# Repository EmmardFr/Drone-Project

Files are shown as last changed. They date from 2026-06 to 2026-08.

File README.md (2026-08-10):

# Drone-Project

- `Hardware/` contains hardware design files:
  - `Datasheets/`: component datasheets (IMUs, barometers, and related parts) used during hardware selection.
  - `Graphics/`: project graphics and visual assets.
  - `Schematics/`: standalone schematic libraries/references for key components (e.g., sensors and Teensy 4.1).
  - PCB designs, in development order:
    1. `ismd_flight_computer (obselete)/` (deprecated early prototype): initial all-in-one flight-computer concept combining Teensy 4.1, multiple IMU/barometer options, and onboard power circuitry.
    2. `ismd_fc_sensortest/`: dedicated sensor test board used to compare multiple IMU and barometer options around a Teensy 4.1 base.
    3. `Carrier_PCB/`: first carrier board revision for system integration (power distribution, receiver I/O, ESC/motor signal breakout, and module connectors).
    4. `Carrier_PCB_v2/`: second carrier board revision refining the carrier design and production-ready outputs.
- `software/` contains firmware, libraries, and software tooling.

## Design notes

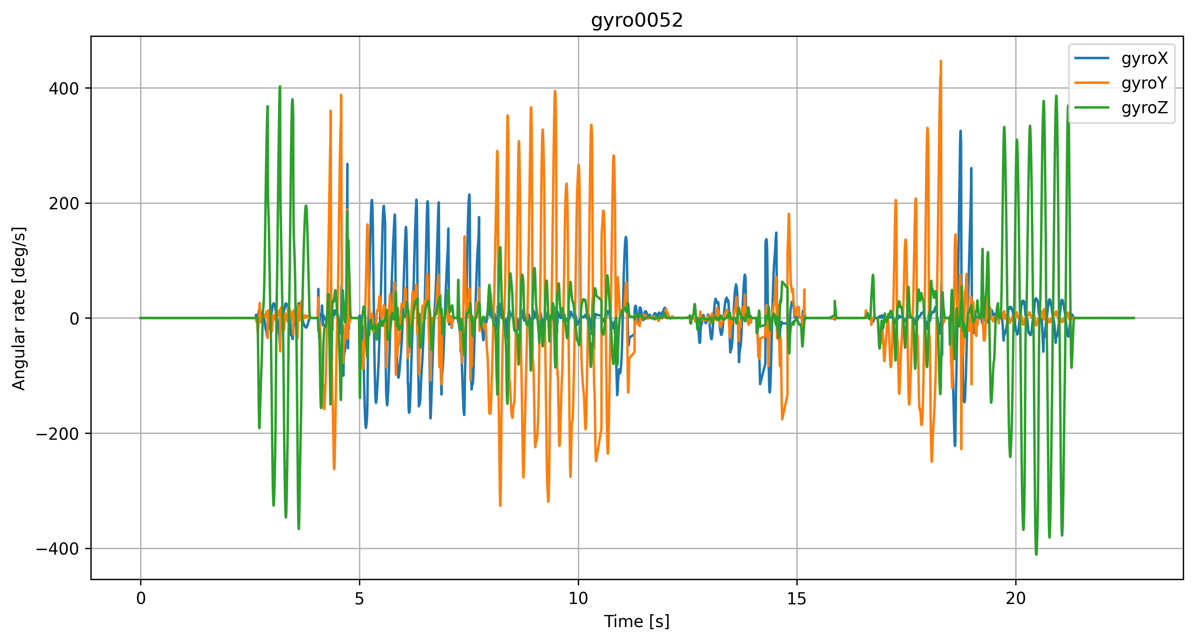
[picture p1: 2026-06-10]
software/Teensy Dev Gyro Plots/gyro0052.png

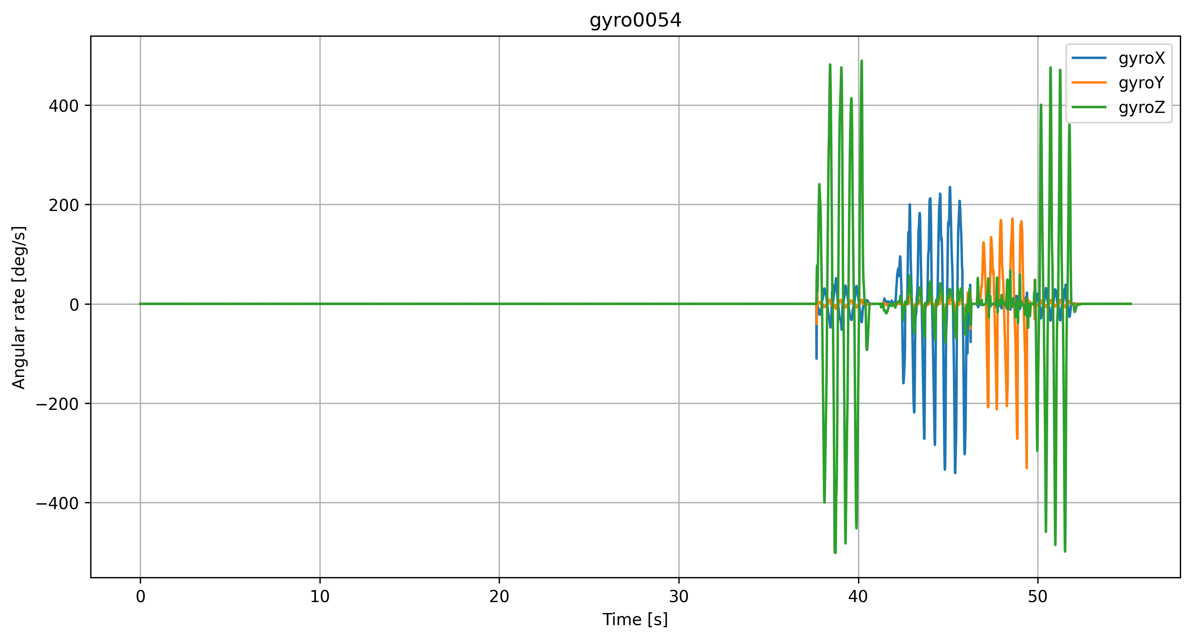
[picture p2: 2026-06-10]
software/Teensy Dev Gyro Plots/gyro0054.png

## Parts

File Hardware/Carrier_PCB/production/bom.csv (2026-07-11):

Designator | Footprint | Quantity | Value | LCSC Part #
3V3, 5V, INT, M1, M2, M3, M4, NCS, SBUS, SCLK, SD0, SDI, SPORT, TLM | TestPoint_Bridge_Pitch2.54mm_Drill0.7mm | 14 | TestPoint
C1 | 1206 | 1 | 10u
C2, C3 | 0805 | 2 | 100n
D1 | 0805 | 1 | LED
ESC1 | PinHeader_1x08_P2.54mm_Horizontal | 1 | Conn_01x08
ESC2 | JST_SH_SM08B-SRSS-TB_1x08-1MP_P1.00mm_Horizontal | 1 | Conn_01x08
GND | PinHeader_1x01_P2.54mm_Horizontal | 1 | Conn_01x01
J1, J2 | PinSocket_1x24_P2.54mm_Vertical | 2 | Conn_01x24
MPU | PinSocket_1x10_P2.54mm_Vertical | 1 | Conn_01x10
R1 | 0805 | 1 | 300
R2 | 0603 | 1 | 10K
R3 | 0603 | 1 | 20K
RXSR_2 | Molex_PicoBlade_53261-0471_1x04-1MP_P1.25mm_Horizontal | 1 | Conn_01x04
RXSR | PinHeader_1x04_P2.54mm_Horizontal | 1 | Conn_01x04

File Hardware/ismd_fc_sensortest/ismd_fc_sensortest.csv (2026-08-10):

Reference | Qty | Value | DNP | Exclude from BOM | Exclude from Board | Footprint | Datasheet
B1 | 1 | BMP581 |  |  |  | BMP581:BMP581
B2 | 1 | DPS368 |  |  |  | DPS368:LGA8S145X65P2X4_200X250X110-V
B3 | 1 | ICP-20100 |  |  |  | ICP-20100:PQFN50P200X200X85-10N
B4 | 1 | MS5611 |  |  |  | MS5611:SON125P500X300X100-8N
B5 | 1 | LPS22DF |  |  |  | Package_LGA:ST_HLGA-10_2x2mm_P0.5mm_LayoutBorder3x2y | https://www.st.com/resource/en/datasheet/lps22df.pdf
C1,C2,C3,C4,C5,C6,C7,C8,C9,C13,C14,C15,C16,C17,C18 | 15 | 100nF |  |  |  | Capacitor_SMD:C_0201_0603Metric
C10 | 1 | 0.1uF |  |  |  | Capacitor_SMD:C_0201_0603Metric
C11 | 1 | 2.2uF |  |  |  | Capacitor_SMD:C_0201_0603Metric
C12 | 1 | 10nF |  |  |  | Capacitor_SMD:C_0201_0603Metric
I1 | 1 | ICM-42688-P |  |  |  | ICM-42688-P:PQFN50P300X250X97-14N
I2 | 1 | BMI088 |  |  |  | Package_LGA:Bosch_LGA-16_4.5x3mm_P0.5mm_LayoutBorder7x1y_ClockwisePinNumbering | https://www.bosch-sensortec.com/media/boschsensortec/downloads/datasheets/bst-bmi088-ds001.pdf
I3 | 1 | BMI270 |  |  |  | BMI270:XDCR_BMI270
I4 | 1 | ISM330DLC |  |  |  | ISM330DLCTR:PQFN50P250X300X86-14N
U1 | 1 | TEENSY_4.1 |  |  |  | TEENSY_4.1:TEENSY41

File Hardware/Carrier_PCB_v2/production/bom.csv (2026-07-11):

Designator | Footprint | Quantity | Value | LCSC Part #
3V1, 5V1, INT1, M1, M2, M3, M4, NCS1, SBUS1, SCLK1, SDI1, SDO1, SPORT1, TLM1 | TestPoint_Keystone_5005-5009_Compact | 14 | 5009
C1 | 1206 | 1 | CL31A106KBHNNNE
C2, C3 | 0805 | 2 | CC0805KRX7R9BB104
D1 | 0805 | 1 | NCD0805R1
ESC1 | PinHeader_1x08_P2.54mm_Horizontal | 1 | HXPZ2.54-1x8PWZ
ESC2 | JST_SH_SM08B-SRSS-TB_1x08-1MP_P1.00mm_Horizontal | 1 | SM08B-SRSS-TB(LF)(SN)
GND1 | TestPoint_Keystone_5010-5014_Multipurpose | 1 | 5011
J1, J2 | PinSocket_1x24_P2.54mm_Vertical | 2 | HC-PM254-8.5H-1x24PZ
MPU1 | PinSocket_1x10_P2.54mm_Vertical | 1 | PM2.54-1*10
R1 | 0805 | 1 | 0805W8F3000T5E
R2 | 0603 | 1 | 0603WAF1002T5E
R3 | 0603 | 1 | 0603WAF2002T5E
RXSR1 | PinHeader_1x04_P2.54mm_Horizontal | 1 | HC-PZ254-13.8L-1x4PWA
RXSR2 | Molex_PicoBlade_53261-0471_1x04-1MP_P1.25mm_Horizontal | 1 | 532610471

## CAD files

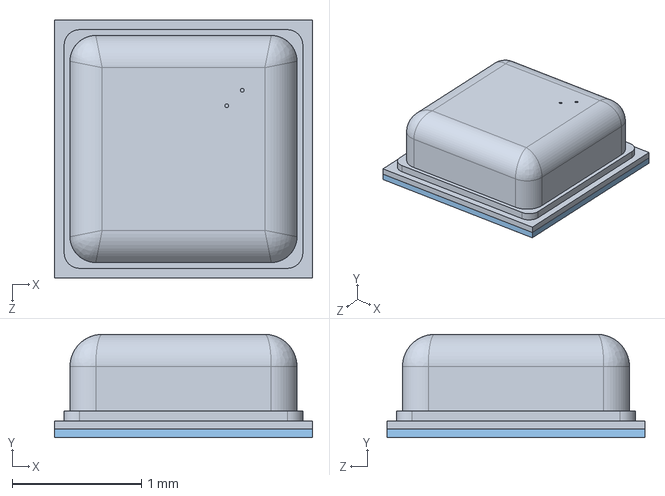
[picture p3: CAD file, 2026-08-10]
Hardware/Schematics/BMP581/BMP581.step
2.00 x 0.801 x 2.00 mm

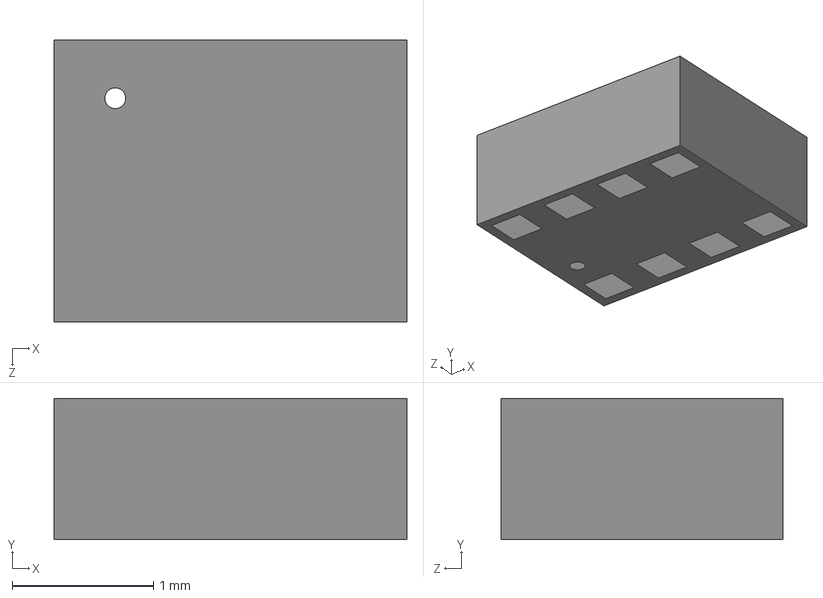
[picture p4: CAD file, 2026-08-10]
Hardware/Schematics/DPS310/DPS310XTSA1.step
2.50 x 1.00 x 2.00 mm

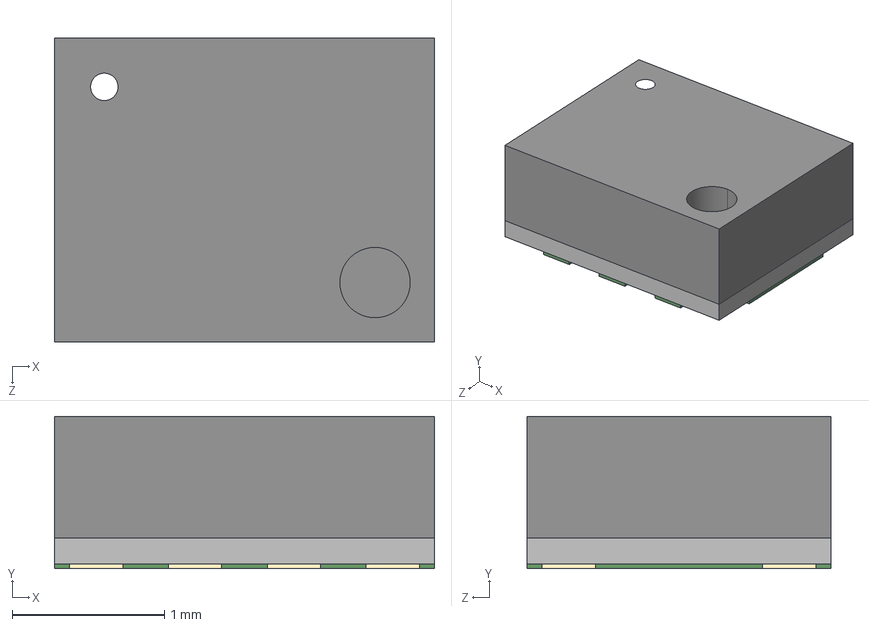
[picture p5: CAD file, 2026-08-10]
Hardware/Schematics/DPS368/DPS368.step
2.50 x 1.00 x 2.00 mm

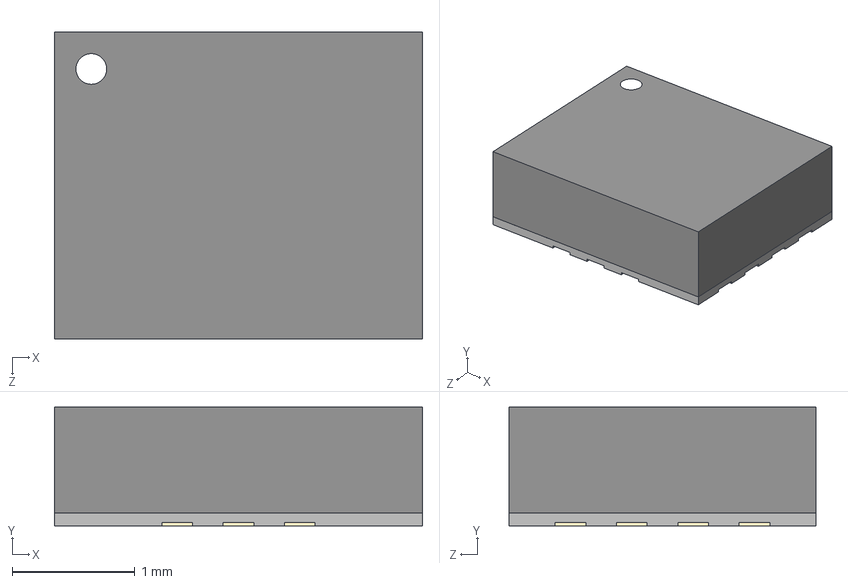
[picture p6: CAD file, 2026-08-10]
Hardware/Schematics/ICM-42688-P/ICM-42688-P.step
3.00 x 0.97 x 2.50 mm

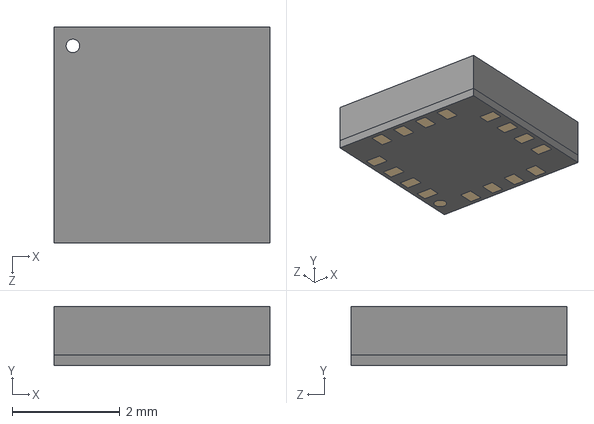
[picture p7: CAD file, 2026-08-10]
Hardware/Schematics/L3G4200D/L3G4200D.step
4.00 x 1.10 x 4.00 mm

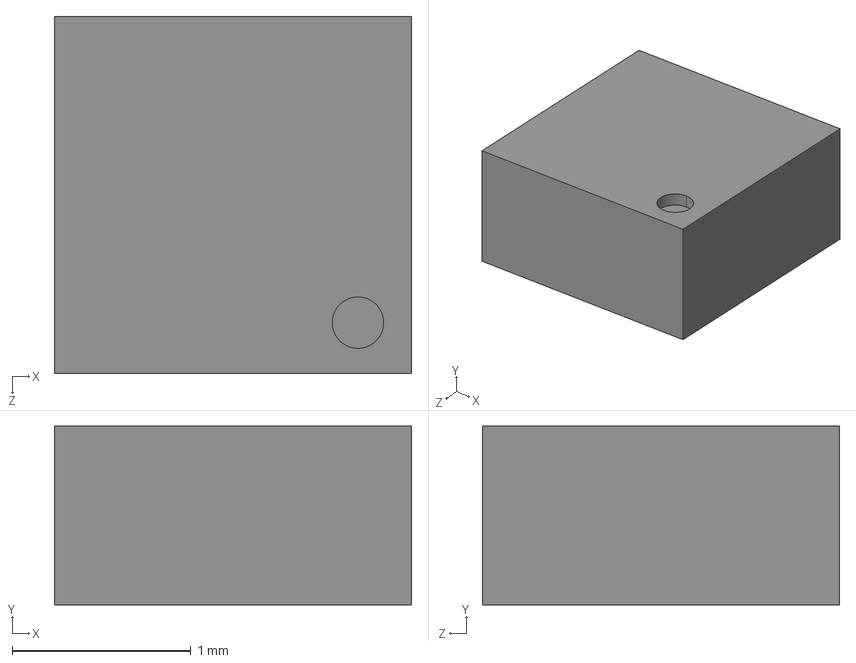
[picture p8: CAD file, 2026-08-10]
Hardware/Schematics/LSM303AGR/LSM303AGR.step
2.00 x 1.00 x 2.00 mm

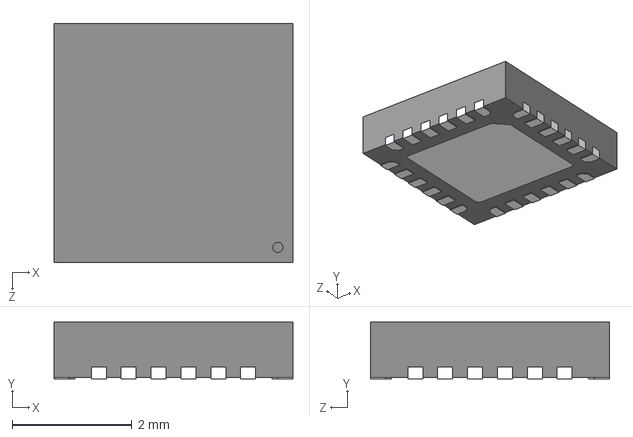
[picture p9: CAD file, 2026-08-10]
Hardware/Schematics/MPU-6050/MPU-6050.step
4.00 x 0.95 x 4.00 mm

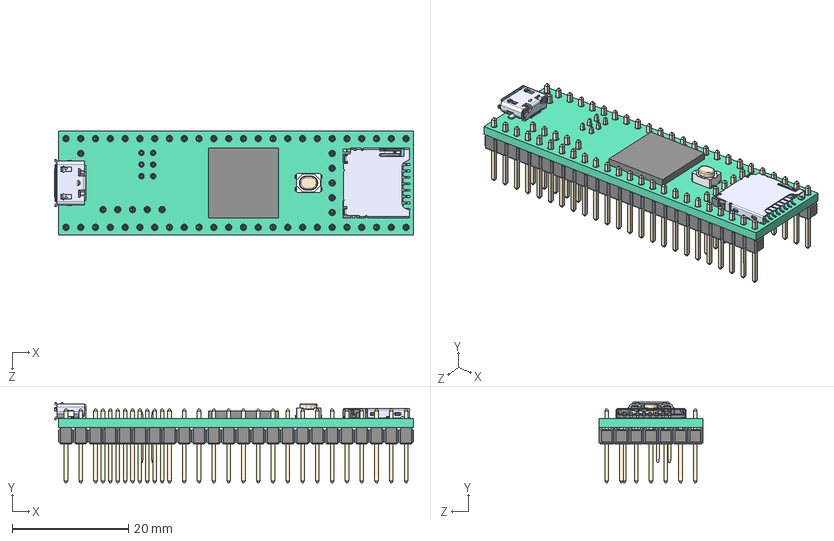
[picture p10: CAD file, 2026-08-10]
Hardware/Schematics/TEENSY_4.1/TEENSY_4.1.step
61.7 x 13.8 x 17.8 mm

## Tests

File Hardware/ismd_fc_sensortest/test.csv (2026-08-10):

Ref | x | y
H1 | 100.000000 | -130.500000
H2 | 130.500000 | -130.500000
H3 | 182.500000 | -100.000000
H4 | 152.000000 | -130.500000
H5 | 182.500000 | -130.500000
H6 | 100.000000 | -100.000000
H7 | 130.500000 | -100.000000
H8 | 152.000000 | -100.000000
H9 | 100.430000 | -110.200000
H10 | 120.430000 | -110.200000

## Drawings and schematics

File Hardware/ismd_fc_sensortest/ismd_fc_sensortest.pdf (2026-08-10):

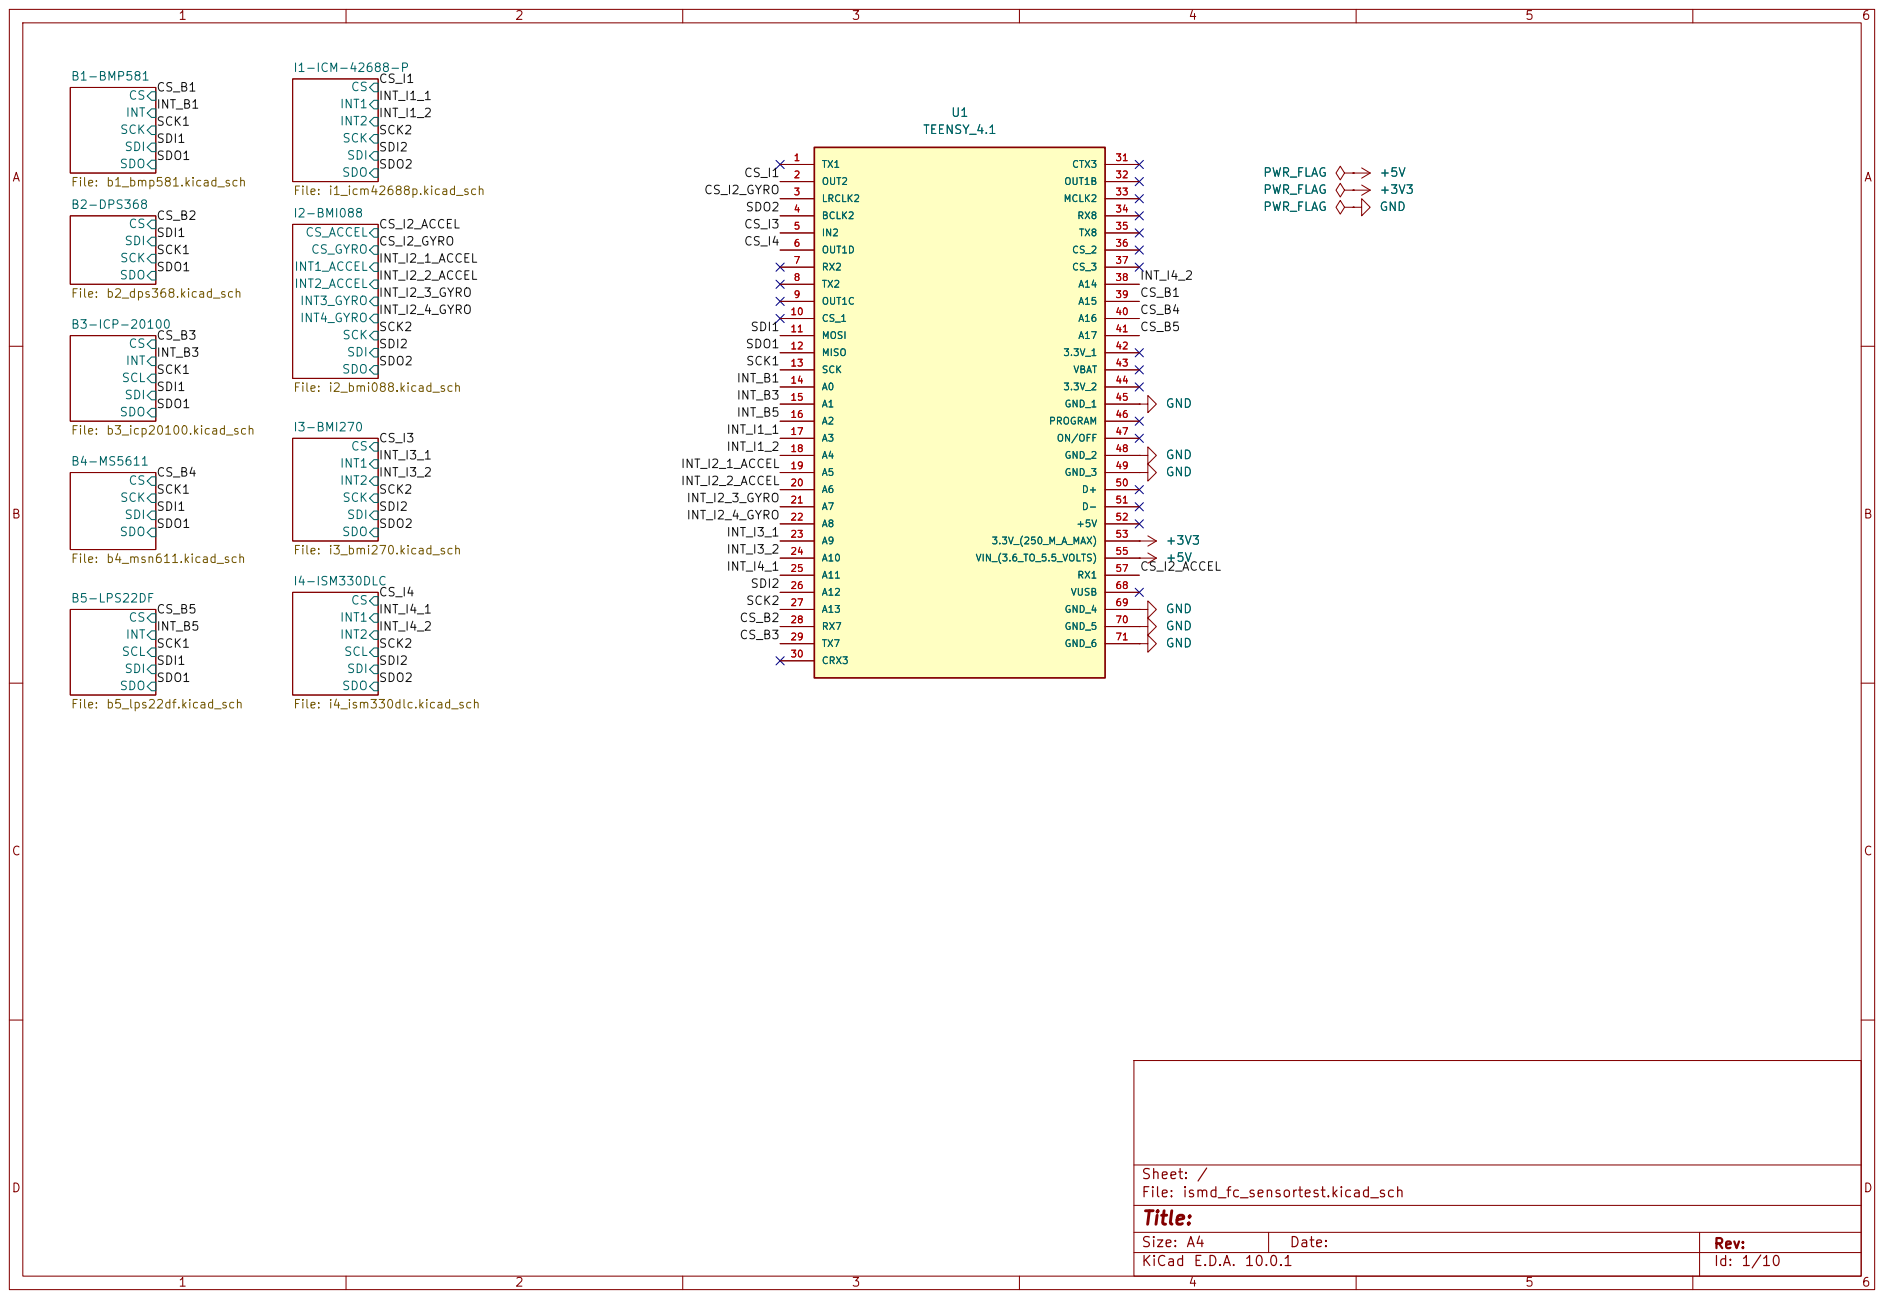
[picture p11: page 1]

Size: A4 | Rev:
KiCad E.D.A. 10.0.1 | Id: 1/10

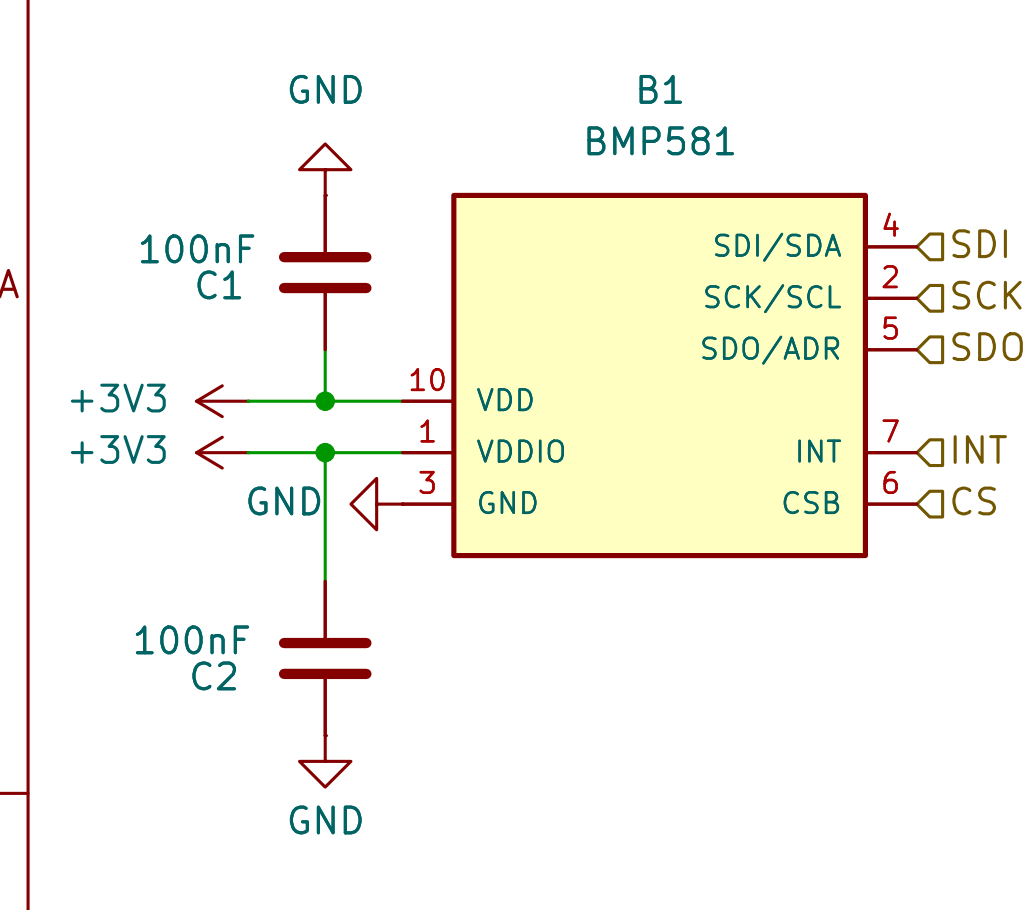
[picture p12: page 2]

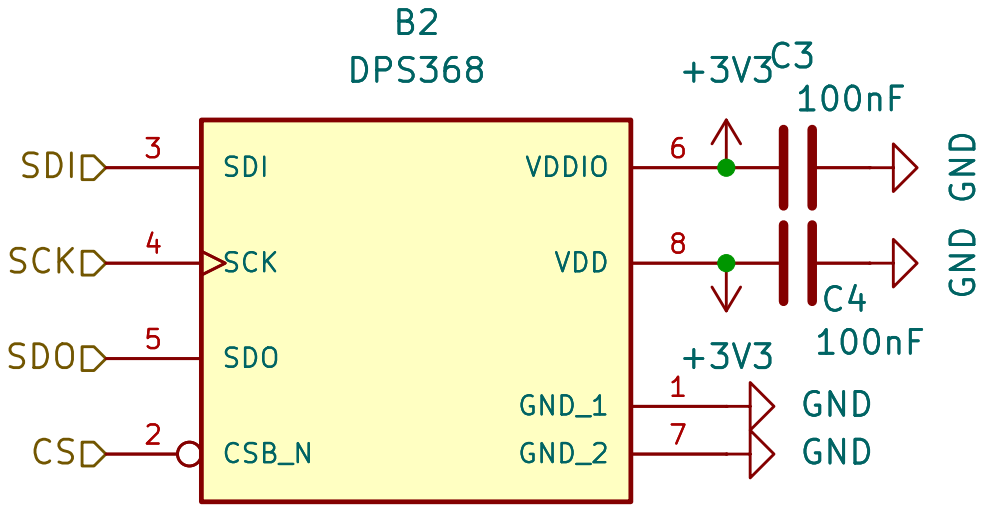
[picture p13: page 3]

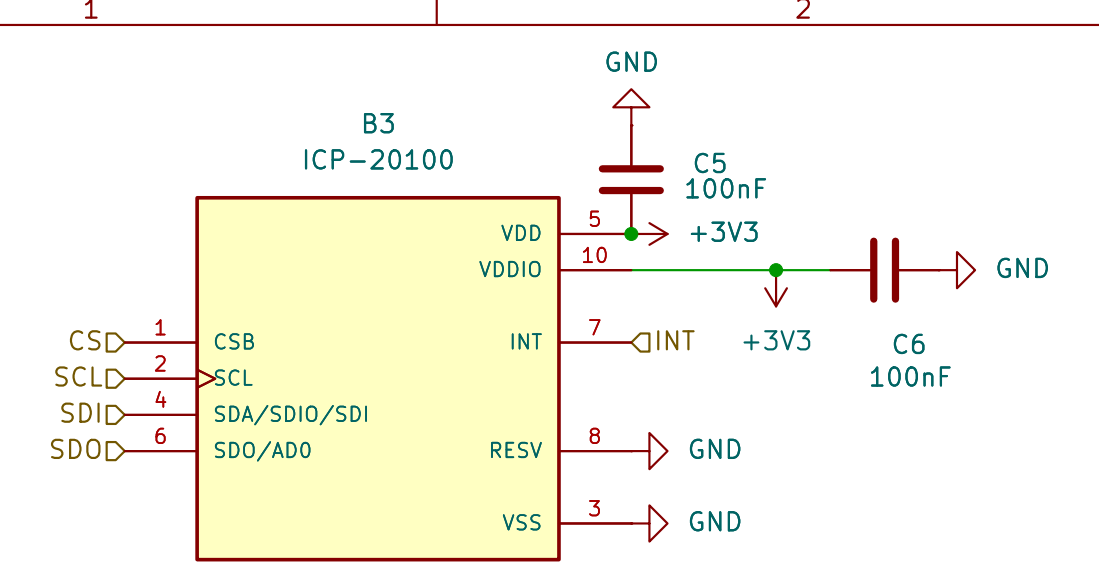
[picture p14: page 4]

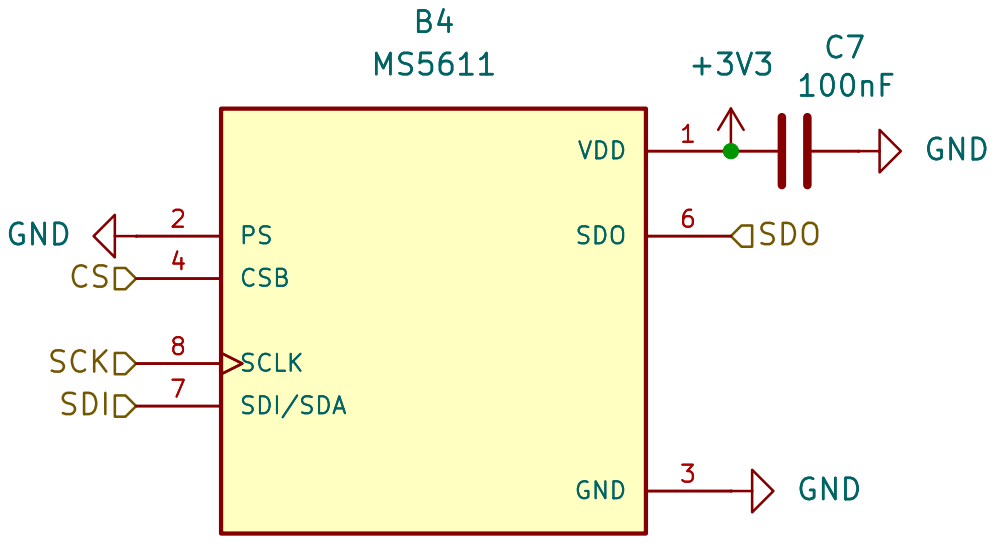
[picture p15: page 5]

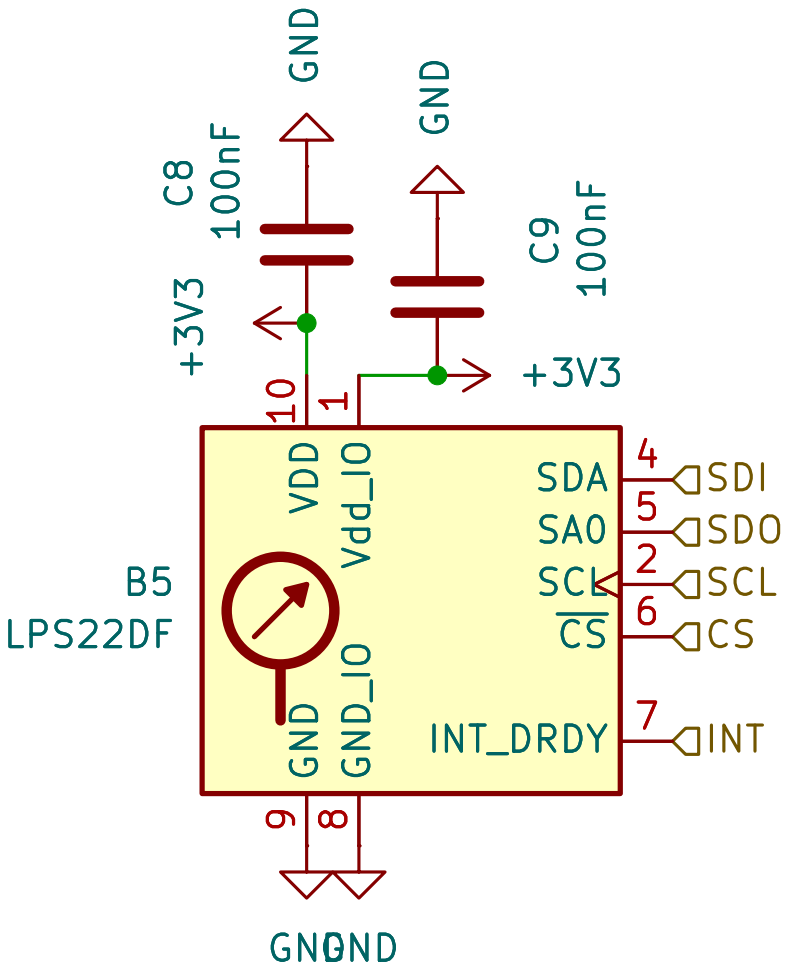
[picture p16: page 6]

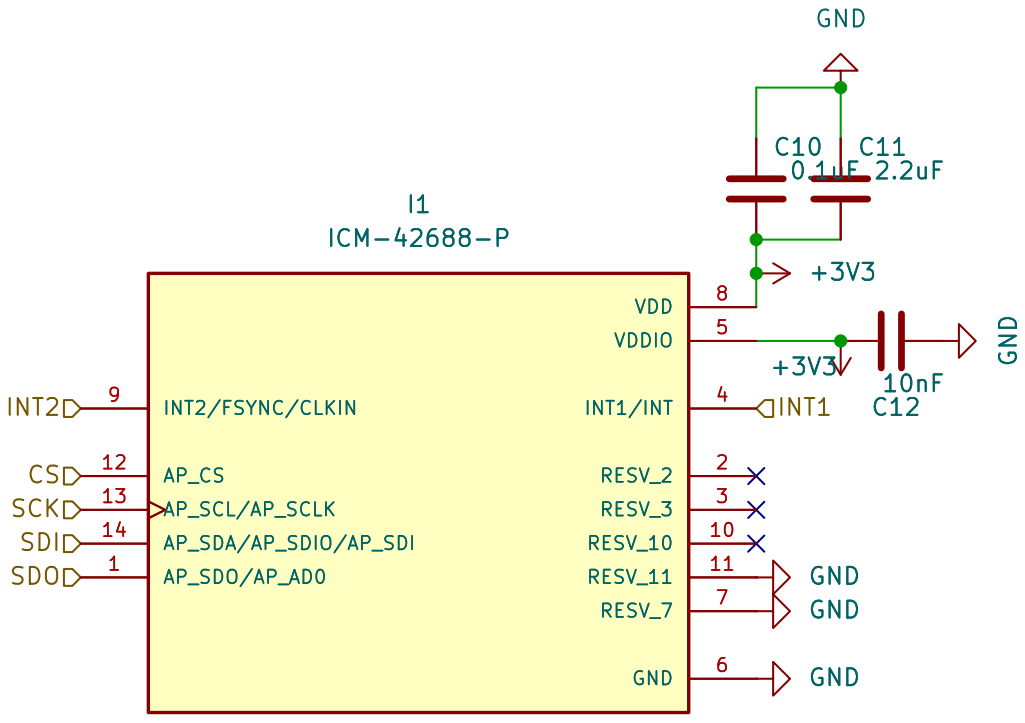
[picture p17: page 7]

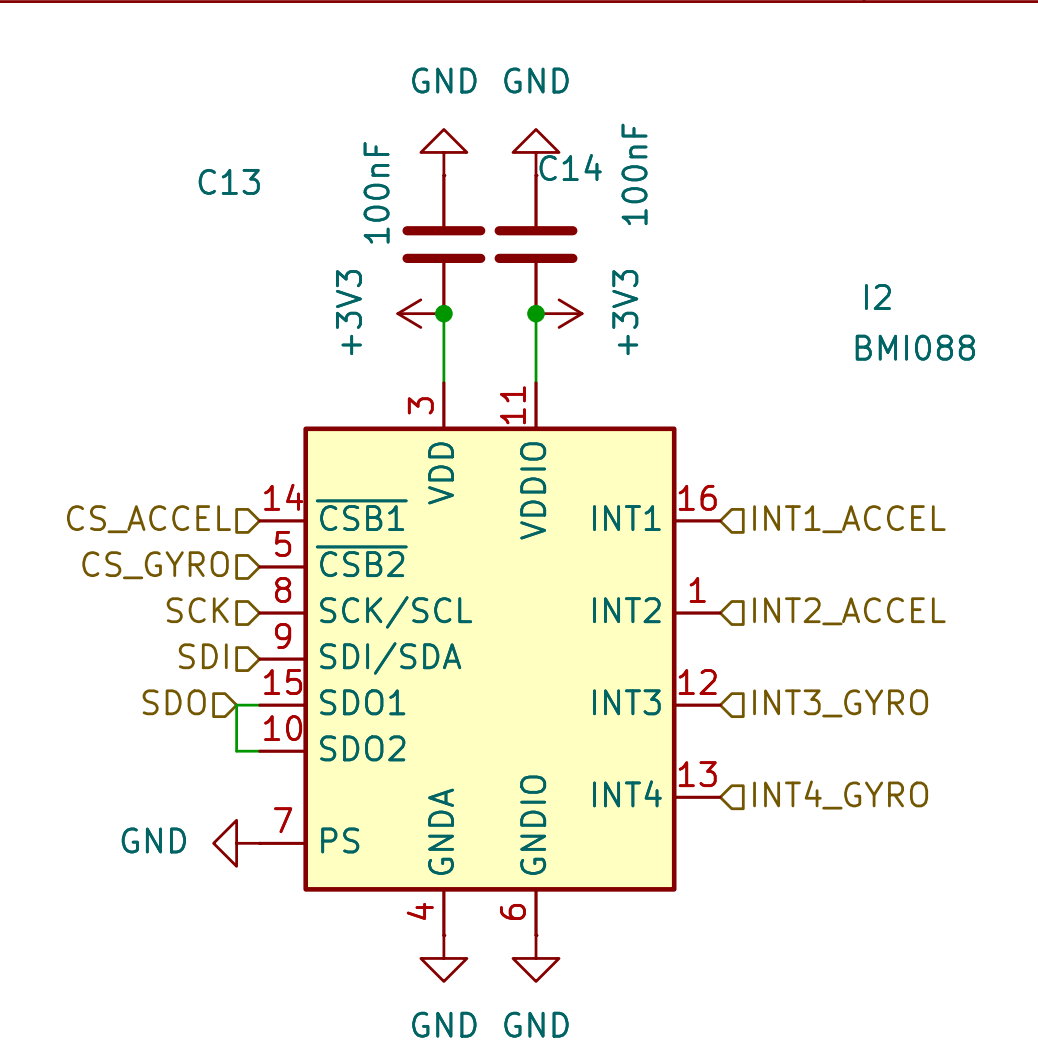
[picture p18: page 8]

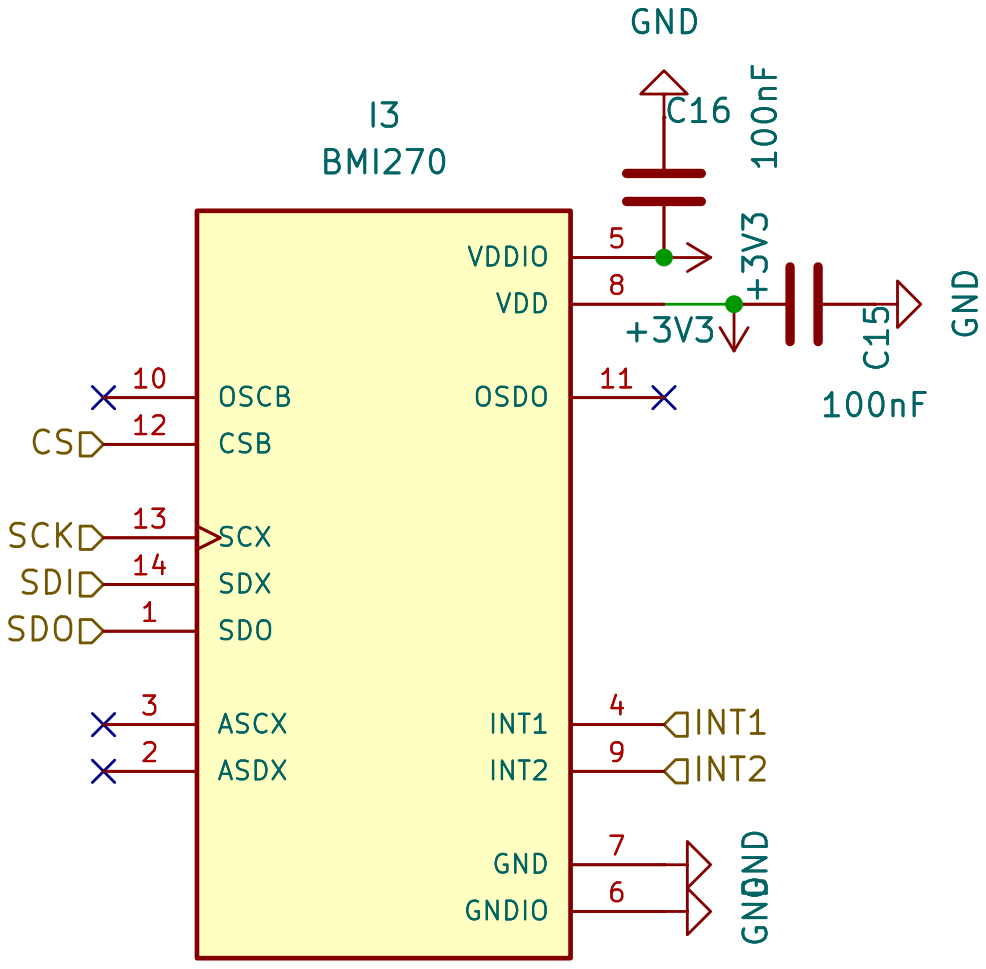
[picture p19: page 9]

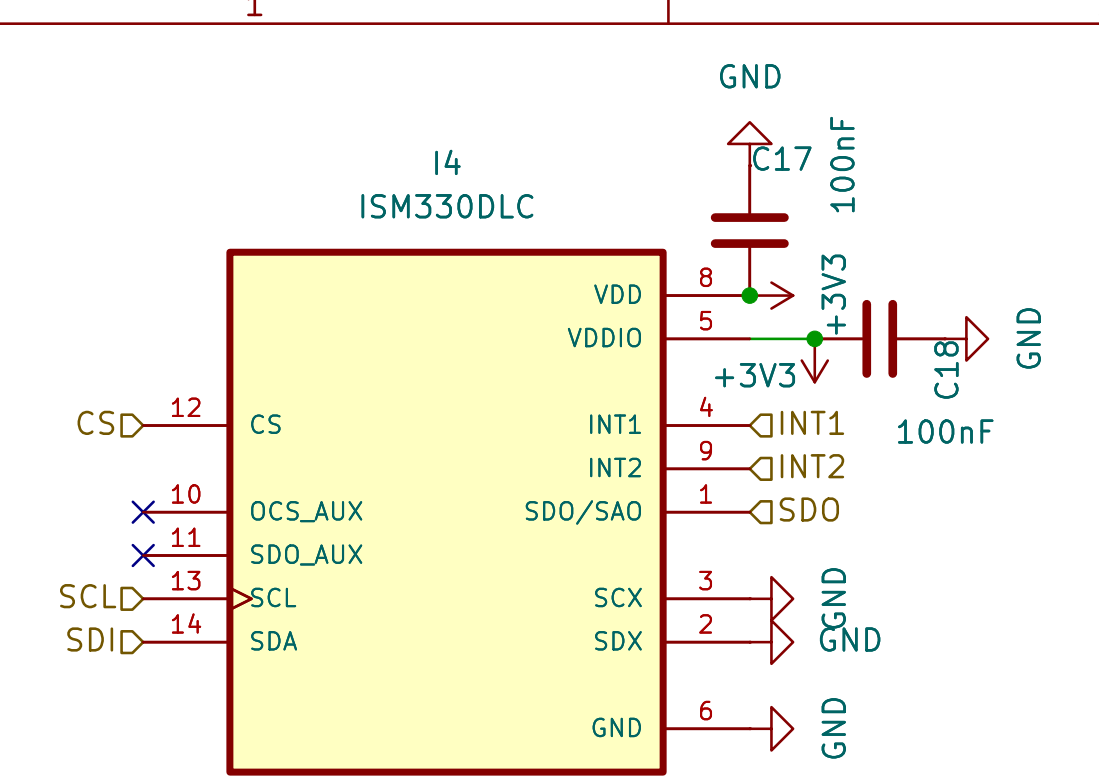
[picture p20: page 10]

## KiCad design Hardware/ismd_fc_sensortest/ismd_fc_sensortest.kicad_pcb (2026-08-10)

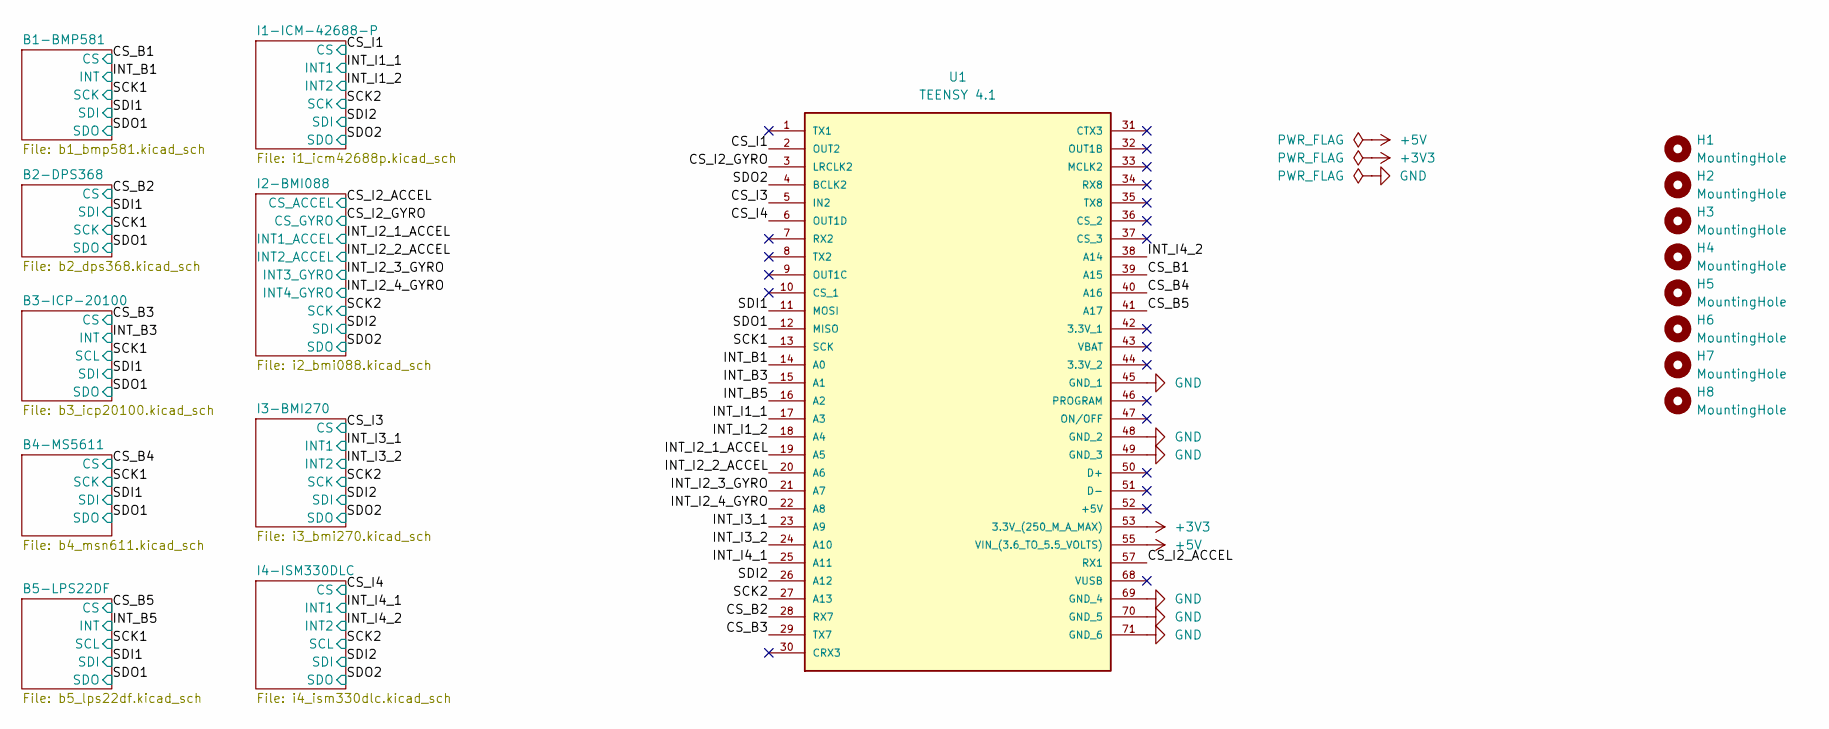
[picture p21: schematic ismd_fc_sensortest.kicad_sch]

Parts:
H1, H2, H3, H4, H5, H6, H7, H8: MountingHole; MountingHole_4mm
U1: TEENSY 4.1; TEENSY41; Manufacturer_Part_Number TEENSY 4.1

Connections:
+3V3: U1.53 (3.3V_(250_M_A_MAX)); also elsewhere on the board
+5V: U1.55 (VIN_(3.6_TO_5.5_VOLTS))
/CS_B1: U1.39 (A15); also elsewhere on the board
/CS_B2: U1.28 (RX7); also elsewhere on the board
/CS_B3: U1.29 (TX7); also elsewhere on the board
/CS_B4: U1.40 (A16); also elsewhere on the board
/CS_B5: U1.41 (A17); also elsewhere on the board
/CS_I1: U1.2 (OUT2); also elsewhere on the board
/CS_I2_ACCEL: U1.57 (RX1); also elsewhere on the board
/CS_I2_GYRO: U1.3 (LRCLK2); also elsewhere on the board
/CS_I3: U1.5 (IN2); also elsewhere on the board
/CS_I4: U1.6 (OUT1D); also elsewhere on the board
/INT_B1: U1.14 (A0); also elsewhere on the board
/INT_B3: U1.15 (A1); also elsewhere on the board
/INT_B5: U1.16 (A2); also elsewhere on the board
/INT_I1_1: U1.17 (A3); also elsewhere on the board
/INT_I1_2: U1.18 (A4); also elsewhere on the board
/INT_I2_1_ACCEL: U1.19 (A5); also elsewhere on the board
/INT_I2_2_ACCEL: U1.20 (A6); also elsewhere on the board
/INT_I2_3_GYRO: U1.21 (A7); also elsewhere on the board
/INT_I2_4_GYRO: U1.22 (A8); also elsewhere on the board
/INT_I3_1: U1.23 (A9); also elsewhere on the board
/INT_I3_2: U1.24 (A10); also elsewhere on the board
/INT_I4_1: U1.25 (A11); also elsewhere on the board
/INT_I4_2: U1.38 (A14); also elsewhere on the board
/SCK1: U1.13 (SCK); also elsewhere on the board
/SCK2: U1.27 (A13); also elsewhere on the board
/SDI1: U1.11 (MOSI); also elsewhere on the board
/SDI2: U1.26 (A12); also elsewhere on the board
/SDO1: U1.12 (MISO); also elsewhere on the board
/SDO2: U1.4 (BCLK2); also elsewhere on the board
GND: U1.45 (GND_1), U1.48 (GND_2), U1.49 (GND_3), U1.69 (GND_4), U1.70 (GND_5), U1.71 (GND_6); also elsewhere on the board

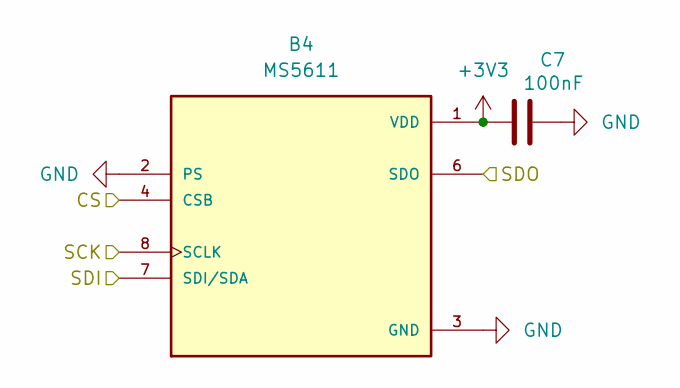
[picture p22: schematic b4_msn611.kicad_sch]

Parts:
B4: MS5611; SON125P500X300X100-8N; PARTREV 06/2017
C7: 100nF; C_0402_1005Metric

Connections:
+3V3: B4.1 (VDD), C7.2; also elsewhere on the board
/CS_B4: B4.4 (CSB), B4.5 (CSB); also elsewhere on the board
/SCK1: B4.8 (SCLK); also elsewhere on the board
/SDI1: B4.7 (SDI/SDA); also elsewhere on the board
/SDO1: B4.6 (SDO); also elsewhere on the board
GND: B4.2 (PS), B4.3 (GND), C7.1; also elsewhere on the board

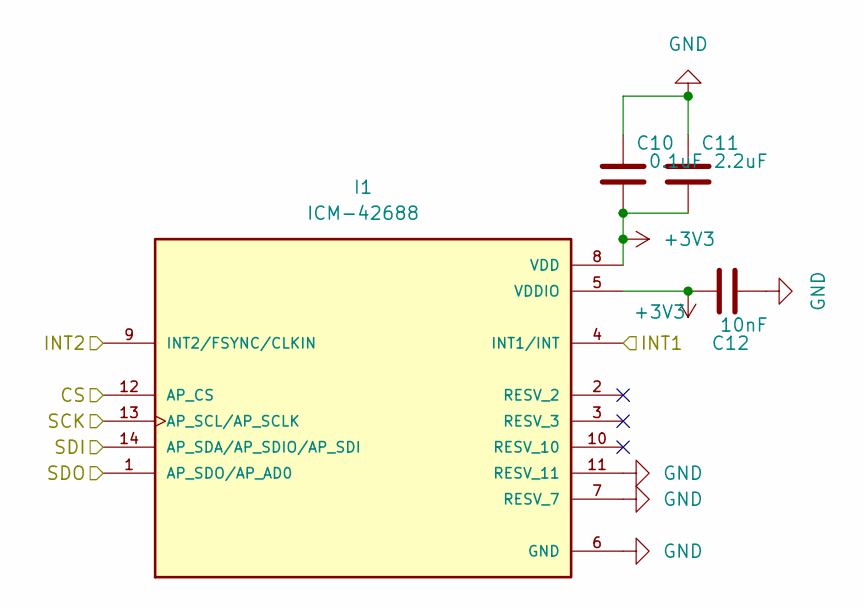
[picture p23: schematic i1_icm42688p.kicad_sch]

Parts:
C10: 0.1uF; C_0402_1005Metric
C11: 2.2uF; C_0402_1005Metric
C12: 10nF; C_0402_1005Metric
I1: ICM-42688; PQFN50P300X250X97-14N; PARTREV 1.2

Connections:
+3V3: C10.2, C11.2, C12.1, I1.5 (VDDIO), I1.8 (VDD); also elsewhere on the board
/CS_I1: I1.12 (AP_CS); also elsewhere on the board
/INT_I1_1: I1.4 (INT1/INT); also elsewhere on the board
/INT_I1_2: I1.9 (INT2/FSYNC/CLKIN); also elsewhere on the board
/SCK2: I1.13 (AP_SCL/AP_SCLK); also elsewhere on the board
/SDI2: I1.14 (AP_SDA/AP_SDIO/AP_SDI); also elsewhere on the board
/SDO2: I1.1 (AP_SDO/AP_AD0); also elsewhere on the board
GND: C10.1, C11.1, C12.2, I1.6 (GND), I1.7 (RESV_7), I1.11 (RESV_11); also elsewhere on the board

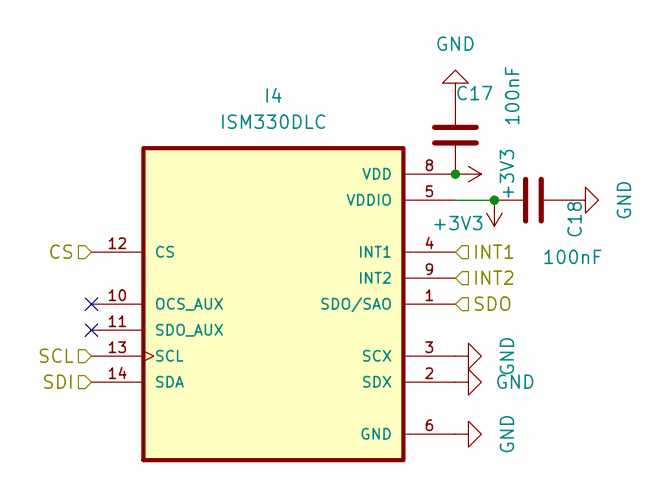
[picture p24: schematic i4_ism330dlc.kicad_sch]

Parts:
C17, C18: 100nF; C_0402_1005Metric
I4: ISM330DLC; PQFN50P250X300X86-14N; PARTREV 2

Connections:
+3V3: C17.1, C18.1, I4.5 (VDDIO), I4.8 (VDD); also elsewhere on the board
/CS_I4: I4.12 (CS); also elsewhere on the board
/INT_I4_1: I4.4 (INT1); also elsewhere on the board
/INT_I4_2: I4.9 (INT2); also elsewhere on the board
/SCK2: I4.13 (SCL); also elsewhere on the board
/SDI2: I4.14 (SDA); also elsewhere on the board
/SDO2: I4.1 (SDO/SAO); also elsewhere on the board
GND: C17.2, C18.2, I4.2 (SDX), I4.3 (SCX), I4.6 (GND), I4.7 (GND); also elsewhere on the board

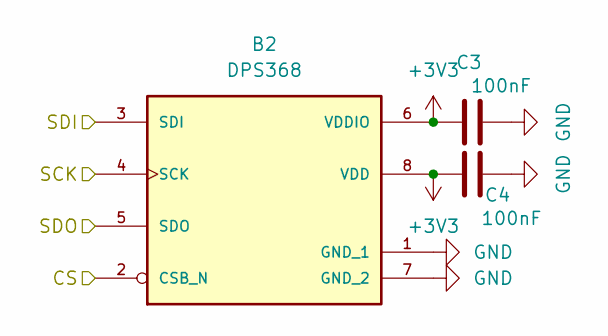
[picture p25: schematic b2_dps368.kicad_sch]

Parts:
B2: DPS368; LGA8S145X65P2X4_200X250X110-V
C3, C4: 100nF; C_0402_1005Metric

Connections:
+3V3: B2.6 (VDDIO), B2.8 (VDD), C3.1, C4.1; also elsewhere on the board
/CS_B2: B2.2 (CSB_N); also elsewhere on the board
/SCK1: B2.4 (SCK); also elsewhere on the board
/SDI1: B2.3 (SDI); also elsewhere on the board
/SDO1: B2.5 (SDO); also elsewhere on the board
GND: B2.1 (GND_1), B2.7 (GND_2), C3.2, C4.2; also elsewhere on the board

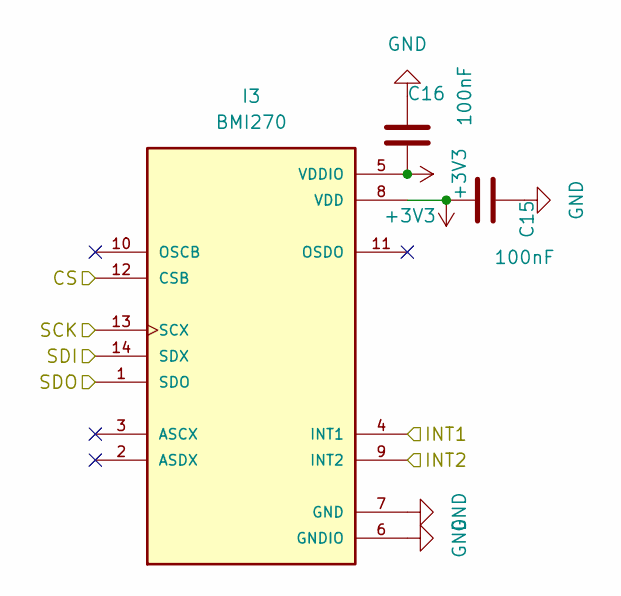
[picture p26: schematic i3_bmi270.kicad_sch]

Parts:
C15, C16: 100nF; C_0402_1005Metric
I3: BMI270; XDCR_BMI270

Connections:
+3V3: C15.1, C16.1, I3.5 (VDDIO), I3.8 (VDD); also elsewhere on the board
/CS_I3: I3.12 (CSB); also elsewhere on the board
/INT_I3_1: I3.4 (INT1); also elsewhere on the board
/INT_I3_2: I3.9 (INT2); also elsewhere on the board
/SCK2: I3.13 (SCX); also elsewhere on the board
/SDI2: I3.14 (SDX); also elsewhere on the board
/SDO2: I3.1 (SDO); also elsewhere on the board
GND: C15.2, C16.2, I3.6 (GNDIO), I3.7 (GND); also elsewhere on the board

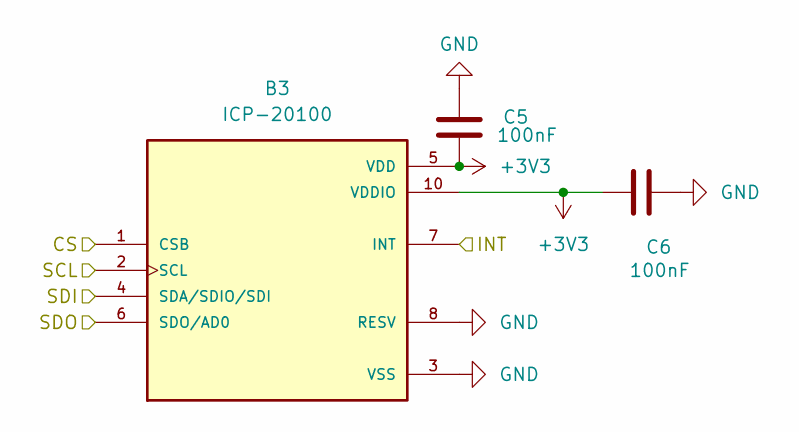
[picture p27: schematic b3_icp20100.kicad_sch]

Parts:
B3: ICP-20100; PQFN50P200X200X85-10N; PARTREV 1.1
C5, C6: 100nF; C_0402_1005Metric

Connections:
+3V3: B3.5 (VDD), B3.10 (VDDIO), C5.2, C6.2; also elsewhere on the board
/CS_B3: B3.1 (CSB); also elsewhere on the board
/INT_B3: B3.7 (INT); also elsewhere on the board
/SCK1: B3.2 (SCL); also elsewhere on the board
/SDI1: B3.4 (SDA/SDIO/SDI); also elsewhere on the board
/SDO1: B3.6 (SDO/AD0); also elsewhere on the board
GND: B3.3 (VSS), B3.8 (RESV), B3.9 (RESV), C5.1, C6.1; also elsewhere on the board

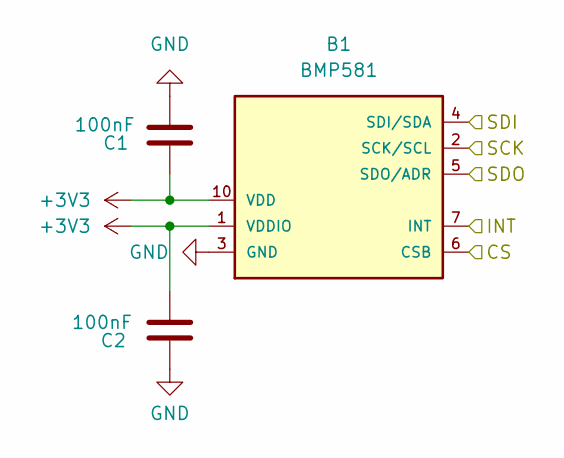
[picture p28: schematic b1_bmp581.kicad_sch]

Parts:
B1: BMP581
C1, C2: 100nF; C_0402_1005Metric

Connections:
+3V3: B1.1 (VDDIO), B1.10 (VDD), C1.1, C2.2; also elsewhere on the board
/CS_B1: B1.6 (CSB); also elsewhere on the board
/INT_B1: B1.7 (INT); also elsewhere on the board
/SCK1: B1.2 (SCK/SCL); also elsewhere on the board
/SDI1: B1.4 (SDI/SDA); also elsewhere on the board
/SDO1: B1.5 (SDO/ADR); also elsewhere on the board
GND: B1.3 (GND), B1.8 (GND), B1.9 (GND), C1.2, C2.1; also elsewhere on the board

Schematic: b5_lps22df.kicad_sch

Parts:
B5: LPS22DF; ST_HLGA-10_2x2mm_P0.5mm_LayoutBorder3x2y
C8, C9: 100nF; C_0402_1005Metric

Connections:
+3V3: B5.1 (Vdd_IO), B5.10 (VDD), C8.2, C9.2; also elsewhere on the board
/CS_B5: B5.6 (~CS); also elsewhere on the board
/INT_B5: B5.7 (INT_DRDY); also elsewhere on the board
/SCK1: B5.2 (SCL); also elsewhere on the board
/SDI1: B5.4 (SDA); also elsewhere on the board
/SDO1: B5.5 (SA0); also elsewhere on the board
GND: B5.3 (GND), B5.8 (GND_IO), B5.9 (GND), C8.1, C9.1; also elsewhere on the board

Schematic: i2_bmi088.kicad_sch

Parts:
C13, C14: 100nF; C_0402_1005Metric
I2: BMI088; Bosch_LGA-16_4.5x3mm_P0.5mm_LayoutBorder7x1y_ClockwisePinNu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

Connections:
+3V3: C13.1, C14.1, I2.3 (VDD), I2.11 (VDDIO); also elsewhere on the board
/CS_I2_ACCEL: I2.14 (~CSB1); also elsewhere on the board
/CS_I2_GYRO: I2.5 (~CSB2); also elsewhere on the board
/INT_I2_1_ACCEL: I2.16 (INT1); also elsewhere on the board
/INT_I2_2_ACCEL: I2.1 (INT2); also elsewhere on the board
/INT_I2_3_GYRO: I2.12 (INT3); also elsewhere on the board
/INT_I2_4_GYRO: I2.13 (INT4); also elsewhere on the board
/SCK2: I2.8 (SCK/SCL); also elsewhere on the board
/SDI2: I2.9 (SDI/SDA); also elsewhere on the board
/SDO2: I2.10 (SDO2), I2.15 (SDO1); also elsewhere on the board
GND: C13.2, C14.2, I2.2 (GNDA), I2.4 (GNDA), I2.6 (GNDIO), I2.7 (PS); also elsewhere on the board

Board: 2 copper layers, 36 parts (0 on the bottom side), 31 nets, no tracks yet.

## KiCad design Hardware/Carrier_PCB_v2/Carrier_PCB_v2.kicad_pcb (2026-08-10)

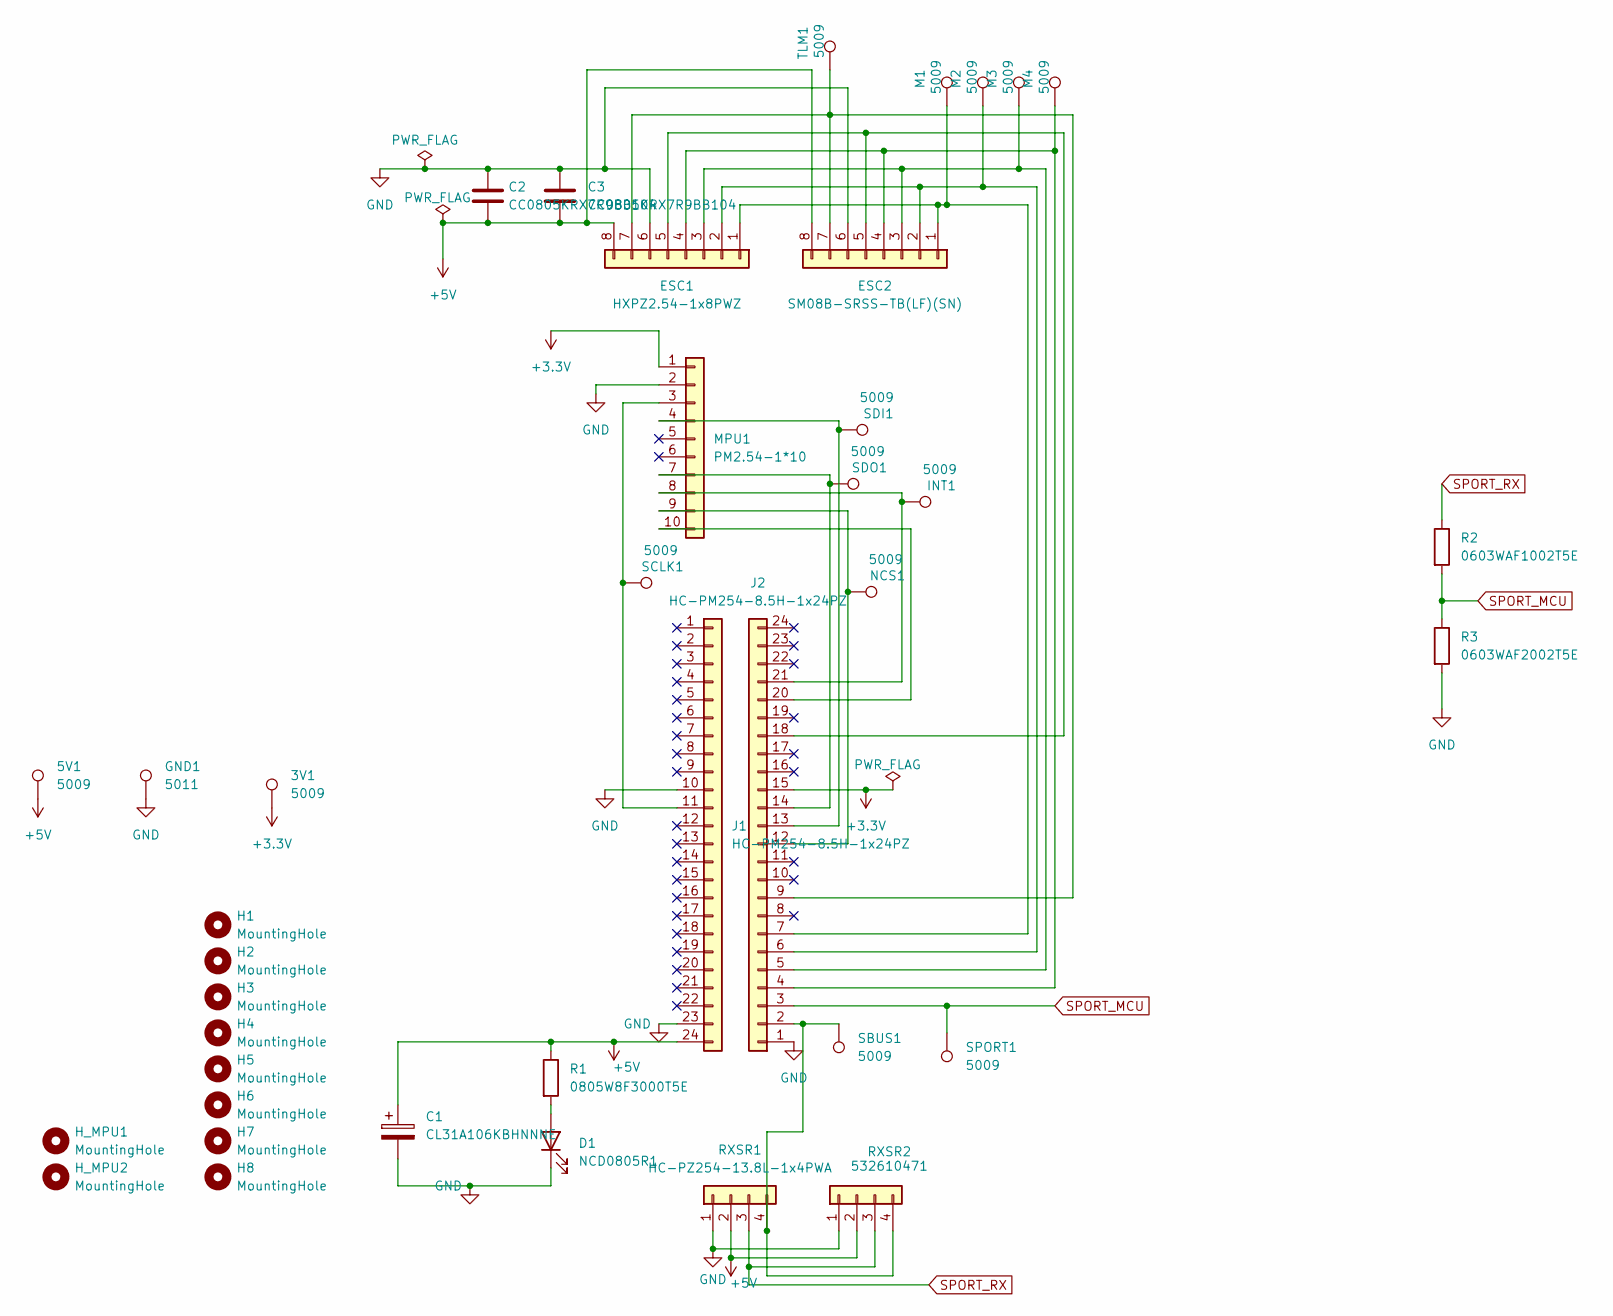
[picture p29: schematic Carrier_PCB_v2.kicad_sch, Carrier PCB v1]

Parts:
3V1, 5V1: 5009; TestPoint_Keystone_5005-5009_Compact
C1: CL31A106KBHNNNE; C_1206_3216Metric
C2, C3: CC0805KRX7R9BB104; C_0805_2012Metric
D1: NCD0805R1; LED_0805_2012Metric
ESC1: HXPZ2.54-1x8PWZ; PinHeader_1x08_P2.54mm_Horizontal
ESC2: SM08B-SRSS-TB(LF)(SN); JST_SH_SM08B-SRSS-TB_1x08-1MP_P1.00mm_Horizontal
GND1: 5011; TestPoint_Keystone_5010-5014_Multipurpose
H1, H2, H3, H4, H5, H6, H7, H8: MountingHole; MountingHole_4mm
H_MPU1, H_MPU2: MountingHole; MountingHole_4mm
INT1: 5009; TestPoint_Keystone_5005-5009_Compact
J1, J2: HC-PM254-8.5H-1x24PZ; PinSocket_1x24_P2.54mm_Vertical
M1, M2, M3, M4: 5009; TestPoint_Keystone_5005-5009_Compact
MPU1: PM2.54-1*10; PinSocket_1x10_P2.54mm_Vertical
NCS1: 5009; TestPoint_Keystone_5005-5009_Compact
R1: 0805W8F3000T5E; R_0805_2012Metric
R2: 0603WAF1002T5E; R_0603_1608Metric
R3: 0603WAF2002T5E; R_0603_1608Metric
RXSR1: HC-PZ254-13.8L-1x4PWA; PinHeader_1x04_P2.54mm_Horizontal
RXSR2: 532610471; Molex_PicoBlade_53261-0471_1x04-1MP_P1.25mm_Horizontal
SBUS1: 5009; TestPoint_Keystone_5005-5009_Compact
SCLK1: 5009; TestPoint_Keystone_5005-5009_Compact
SDI1: 5009; TestPoint_Keystone_5005-5009_Compact
SDO1: 5009; TestPoint_Keystone_5005-5009_Compact
SPORT1: 5009; TestPoint_Keystone_5005-5009_Compact
TLM1: 5009; TestPoint_Keystone_5005-5009_Compact

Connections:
+3.3V: 3V1.1 (1_1), J2.15, MPU1.1
+5V: 5V1.1 (1_1), C1.1, C2.2, C3.2, ESC1.8, ESC2.8, J1.24, R1.1, RXSR1.2, RXSR2.2
GND: C1.2, C2.1, C3.1, D1.1 (K), ESC1.6, ESC2.6, GND1.1 (1_1), J1.10, J1.23, J2.1, MPU1.2, R3.2, RXSR1.1, RXSR2.1
unnamed: D1.2 (A), R1.2
unnamed: ESC1.1, ESC2.1, J2.7, M1.1 (1_1)
unnamed: ESC1.2, ESC2.2, J2.6, M2.1 (1_1)
unnamed: ESC1.3, ESC2.3, J2.5, M3.1 (1_1)
unnamed: ESC1.4, ESC2.4, J2.4, M4.1 (1_1)
unnamed: ESC1.5, ESC2.5, J2.18
unnamed: ESC1.7, ESC2.7, J2.9, TLM1.1 (1_1)
unnamed: J1.11, MPU1.3, SCLK1.1 (1_1)
unnamed: J2.2, RXSR1.4, RXSR2.4, SBUS1.1 (1_1)
unnamed: J2.12, MPU1.9, NCS1.1 (1_1)
unnamed: J2.13, MPU1.4, SDI1.1 (1_1)
unnamed: J2.14, MPU1.7, SDO1.1 (1_1)
unnamed: J2.20, MPU1.10
unnamed: INT1.1 (1_1), J2.21, MPU1.8
SPORT_MCU: J2.3, R2.2, R3.1, SPORT1.1 (1_1)
SPORT_RX: R2.1, RXSR1.3, RXSR2.3

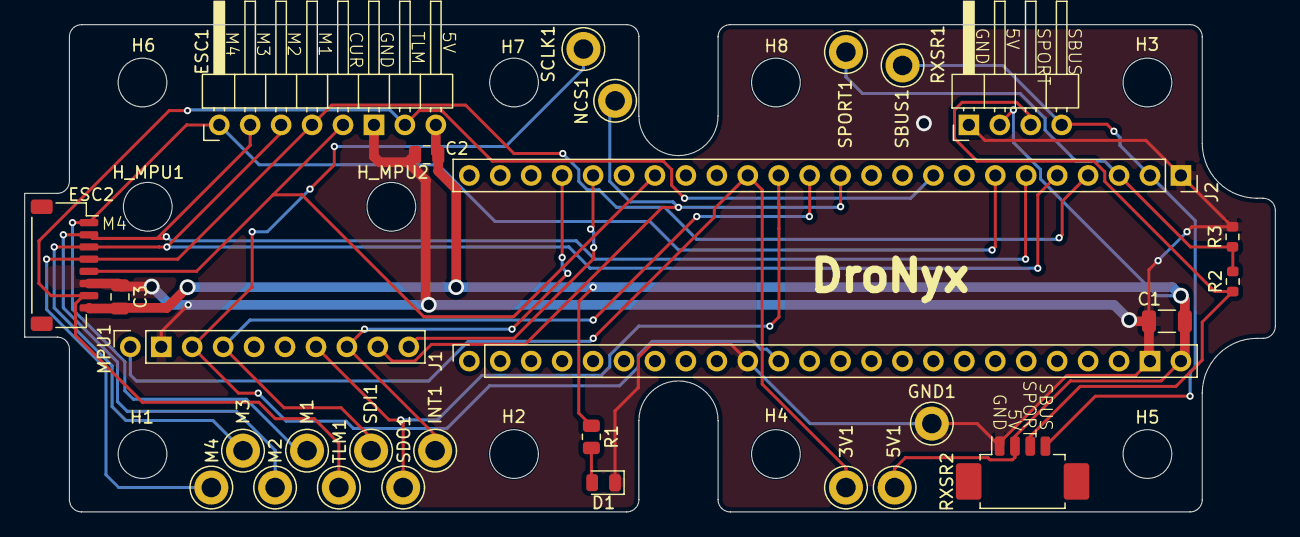
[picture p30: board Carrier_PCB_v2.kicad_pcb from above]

Board: 2 copper layers, 102.7 x 40.0 mm, 39 parts (0 on the bottom side), 19 nets.

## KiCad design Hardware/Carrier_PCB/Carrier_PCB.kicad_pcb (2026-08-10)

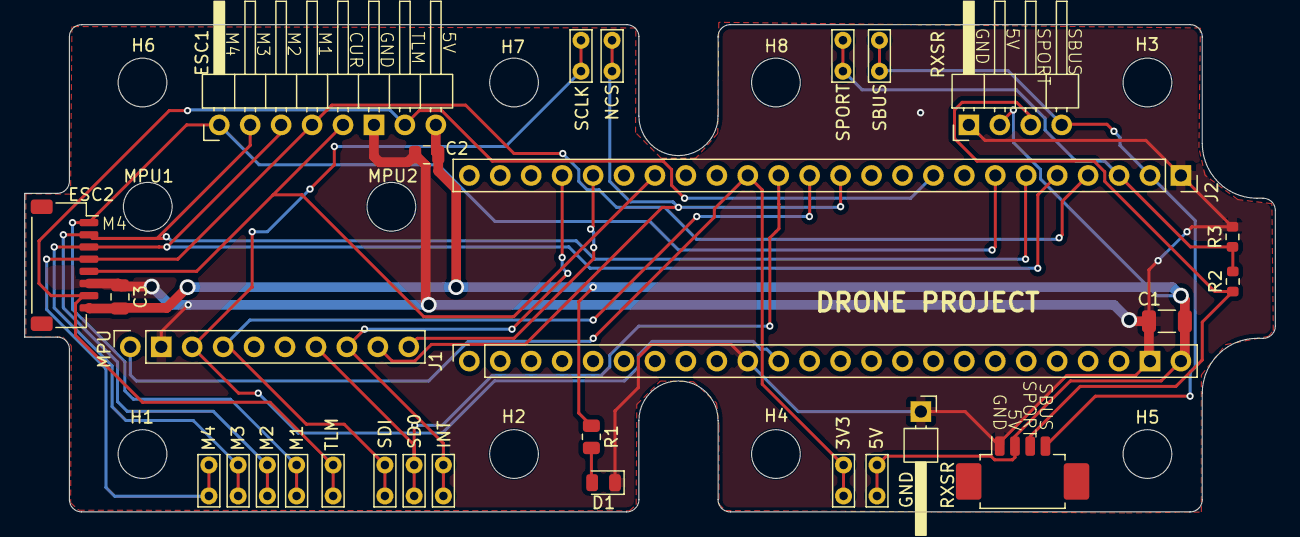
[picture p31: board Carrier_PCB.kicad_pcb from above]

Board: 2 copper layers, 102.7 x 40.0 mm, 39 parts (0 on the bottom side), 19 nets.

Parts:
3V3, 5V: TestPoint; TestPoint_Bridge_Pitch2.54mm_Drill0.7mm
C1: 10u; C_1206_3216Metric
C2, C3: 100n; C_0805_2012Metric
D1: LED; LED_0805_2012Metric
ESC1: Conn_01x08; PinHeader_1x08_P2.54mm_Horizontal
ESC2: Conn_01x08; JST_SH_SM08B-SRSS-TB_1x08-1MP_P1.00mm_Horizontal
GND: Conn_01x01; PinHeader_1x01_P2.54mm_Horizontal
H1, H2, H3, H4, H5, H6, H7, H8: MountingHole; MountingHole_4mm
INT: TestPoint; TestPoint_Bridge_Pitch2.54mm_Drill0.7mm
J1, J2: Conn_01x24; PinSocket_1x24_P2.54mm_Vertical
M1, M2, M3, M4: TestPoint; TestPoint_Bridge_Pitch2.54mm_Drill0.7mm
MPU: Conn_01x10; PinSocket_1x10_P2.54mm_Vertical
MPU1, MPU2: MountingHole; MountingHole_4mm
NCS: TestPoint; TestPoint_Bridge_Pitch2.54mm_Drill0.7mm
R1: 300; R_0805_2012Metric
R2: 10K; R_0603_1608Metric
R3: 20K; R_0603_1608Metric
RXSR: Conn_01x04; PinHeader_1x04_P2.54mm_Horizontal
RXSR#2: Conn_01x04; Molex_PicoBlade_53261-0471_1x04-1MP_P1.25mm_Horizontal
SBUS: TestPoint; TestPoint_Bridge_Pitch2.54mm_Drill0.7mm
SCLK: TestPoint; TestPoint_Bridge_Pitch2.54mm_Drill0.7mm
SD0: TestPoint; TestPoint_Bridge_Pitch2.54mm_Drill0.7mm
SDI: TestPoint; TestPoint_Bridge_Pitch2.54mm_Drill0.7mm
SPORT: TestPoint; TestPoint_Bridge_Pitch2.54mm_Drill0.7mm
TLM: TestPoint; TestPoint_Bridge_Pitch2.54mm_Drill0.7mm

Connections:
+3.3V: 3V3.1 (1_1), J2.15, MPU.1
+5V: 5V.1 (1_1), C1.1, C2.2, C3.2, ESC1.8, ESC2.8, J1.24, R1.1, RXSR.2, RXSR#2.2
GND: C1.2, C2.1, C3.1, D1.1 (K), ESC1.6, ESC2.6, GND.1 (Pin_1_1), J1.10, J1.23, J2.1, MPU.2, R3.2, RXSR.1, RXSR#2.1
unnamed: D1.2 (A), R1.2
unnamed: J1.11, MPU.3, SCLK.1 (1_1)
unnamed: J2.2, RXSR.4, RXSR#2.4, SBUS.1 (1_1)
unnamed: ESC1.4, ESC2.4, J2.4, M4.1 (1_1)
unnamed: ESC1.3, ESC2.3, J2.5, M3.1 (1_1)
unnamed: ESC1.2, ESC2.2, J2.6, M2.1 (1_1)
unnamed: ESC1.1, ESC2.1, J2.7, M1.1 (1_1)
unnamed: ESC1.7, ESC2.7, J2.9, TLM.1 (1_1)
unnamed: J2.12, MPU.9, NCS.1 (1_1)
unnamed: J2.13, MPU.4, SDI.1 (1_1)
unnamed: J2.14, MPU.7, SD0.1 (1_1)
unnamed: ESC1.5, ESC2.5, J2.18
unnamed: J2.20, MPU.10
unnamed: INT.1 (1_1), J2.21, MPU.8
SPORT_MCU: J2.3, R2.2, R3.1, SPORT.1 (1_1)
SPORT_RX: R2.1, RXSR.3, RXSR#2.3

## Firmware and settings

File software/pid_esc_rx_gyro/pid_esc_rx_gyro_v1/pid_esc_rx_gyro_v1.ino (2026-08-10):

#include "gyro.h"
#include "rx.h"
#include "esc.h"
#include "pid.h"
#include "motor_mix.h"
#include "sd_card.h"

constexpr uint32_t LOOP_PERIOD_US = 1000; // 1 kHz

void stopProgram()
{
  if (Serial.available())
  {
    char c = Serial.read();

    if(c == 'q')
    {
      logFile.flush();
      logFile.close();
      rxFlushSD = false;

      while(1);
    }
  }
  if(rxFlushSD)
  {
    logFile.flush();
    logFile.close();
    rxFlushSD = false;

    while(1);
  }
}

void setup()
{
  setupESC();

  ////////////////////////////////////////
  pinMode(LED_BUILTIN, OUTPUT);
  digitalWrite(LED_BUILTIN, LOW);
  ////////////////////////////////////////

  // delay(2000);
  
  Serial.begin(115200);

  pinMode(CS_IMU, OUTPUT);
  digitalWrite(CS_IMU, HIGH);

  SPI.begin();
  delay(50);

  // Gyro setup
  setupGyro();

  // SD card setup
  setupSD();

  // Gyro setup
  setupRx();

}

void loop()
{
  // rx
  if(readSBUS())
  {
    decodeSBUS(frame);
    printRx(0);
  }

  // Control loop
  static uint32_t nextLoop = micros() + LOOP_PERIOD_US;
  if ((int32_t)(micros() - nextLoop) < 0)
    return;

  nextLoop += LOOP_PERIOD_US;

  Gyro raw = readGyro();
  Gyro filteredGyro = filterGyro(raw);

  printGyro(1, filteredGyro);

  MOTOR_POWER motor_power;

  if(rx.armSwitch == 0)
  {
    sendThrottle(MOTOR_STOP, MOTOR_PIN1);
    sendThrottle(MOTOR_STOP, MOTOR_PIN2);
    sendThrottle(MOTOR_STOP, MOTOR_PIN3);
    sendThrottle(MOTOR_STOP, MOTOR_PIN4);

    motor_power = {0,0,0,0};
  }
  else
  {
    computePid(rx.roll, -rx.pitch, -rx.yaw, filteredGyro.y, filteredGyro.x, filteredGyro.z);
    printPID(0);

    motor_power = computePower(rx.throttle, pid.roll, pid.pitch, pid.yaw);
    printMPower(motor_power, 0);
    
    sendThrottle(motor_power.motor1, MOTOR_PIN1);
    sendThrottle(motor_power.motor2, MOTOR_PIN2);
    sendThrottle(motor_power.motor3, MOTOR_PIN3);
    sendThrottle(motor_power.motor4, MOTOR_PIN4);
  }

  loopSD(filteredGyro, motor_power);

  // static uint32_t t = micros();
  // uint32_t dt = micros() - t;
  // t = micros();
  // if(dt > 1006)
  //   Serial.println(dt);

  stopProgram();
}

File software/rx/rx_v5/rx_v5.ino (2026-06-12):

int countSBUS = 0;
int countTot = 0;

struct RCChannels {
  float throttle;
  float roll;
  float pitch;
  float yaw;

  int armSwitch;
  int switch2;
  int switch3;
  int switch4;
  int switch5;
  int switch6;

  float pot1;
  float pot2;

  float ch13;
  float ch14;
  float ch15;
  float ch16;

  bool frameLost;
  bool failsafe;
};

RCChannels rx;

uint8_t frame[25];

bool readSBUS()
{
  static uint8_t idx = 0;

  while(Serial1.available())
  {
    uint8_t b = Serial1.read();

    if(idx == 0 && b != 0x0F)
      continue;

    frame[idx++] = b;

    if(idx == 25)
    {
      idx = 0;

      if(frame[24] == 0x00)
        return true;
    }
  }

  return false;
}

void decodeSBUS(uint8_t frame[25])
{
  rx.throttle   = ((frame[1]       | frame[2] << 8)                     & 0x07FF);
  rx.roll       = ((frame[2] >> 3  | frame[3] << 5)                     & 0x07FF);
  rx.pitch      = ((frame[3] >> 6  | frame[4] << 2 | frame[5] << 10)    & 0x07FF);
  rx.yaw        = ((frame[5] >> 1  | frame[6] << 7)                     & 0x07FF);
  
  rx.armSwitch  = ((frame[6] >> 4  | frame[7] << 4)                     & 0x07FF);
  rx.switch2    = ((frame[7] >> 7  | frame[8] << 1 | frame[9] << 9)     & 0x07FF);
  rx.switch3    = ((frame[9] >> 2  | frame[10] << 6)                    & 0x07FF);
  rx.switch4    = ((frame[10] >> 5 | frame[11] << 3)                    & 0x07FF);
  rx.switch5    = ((frame[12]      | frame[13] << 8)                    & 0x07FF);
  rx.switch6    = ((frame[13] >> 3 | frame[14] << 5)                    & 0x07FF);

  rx.pot1       = ((frame[14] >> 6 | frame[15] << 2 | frame[16] << 10)  & 0x07FF);
  rx.pot2       = ((frame[16] >> 1 | frame[17] << 7)                    & 0x07FF);

  rx.ch13       = ((frame[17] >> 4 | frame[18] << 4)                    & 0x07FF);
  rx.ch14       = ((frame[18] >> 7 | frame[19] << 1 | frame[20] << 9)   & 0x07FF);
  rx.ch15       = ((frame[20] >> 2 | frame[21] << 6)                    & 0x07FF);
  rx.ch16       = ((frame[21] >> 5 | frame[22] << 3)                    & 0x07FF);

  rx.frameLost  =   frame[23] & (1 << 2);
  rx.failsafe   =   frame[23] & (1 << 3);

  normalizeChannels();
}

void normalizeChannels()
{
  rx.throttle   =       rx.throttle / 2000.0;
  rx.roll       =   (rx.roll - 992) / 1000.0;
  rx.pitch      =  (rx.pitch - 992) / 1000.0;
  rx.yaw        =    (rx.yaw - 992) / 1000.0;

  rx.armSwitch  = (rx.armSwitch > 1000) ? 1 : 0;
  rx.switch2    = (rx.switch2 > 1500) ? 1 : ((rx.switch2 < 500) ? -1 : 0);
  rx.switch3    = (rx.switch3 > 1500) ? 1 : ((rx.switch3 < 500) ? -1 : 0);
  rx.switch4    = (rx.switch4 > 1500) ? 1 : ((rx.switch4 < 500) ? -1 : 0);
  rx.switch5    = (rx.switch5 > 1500) ? 1 : ((rx.switch5 < 500) ? -1 : 0);
  rx.switch6    = (rx.switch6 > 1500) ? 1 : ((rx.switch6 < 500) ? -1 : 0);
}

void printRx(bool doIt)
{
  if(doIt)
  {
    Serial.print(rx.throttle);
    Serial.print('\t');
    Serial.print(rx.roll);
    Serial.print('\t');
    Serial.print(rx.pitch);
    Serial.print('\t');
    Serial.print(rx.yaw);
    Serial.print('\t');

    Serial.print(rx.armSwitch);
    Serial.print('\t');
    Serial.print(rx.switch3);
    Serial.print('\t');
    Serial.print(rx.switch4);
    Serial.print('\t');
    Serial.print(rx.switch5);
    Serial.print('\t');
    Serial.print(rx.switch6);
    Serial.print('\t');

    Serial.print(rx.pot1);
    Serial.print('\t');
    Serial.print(rx.pot2);
    Serial.print('\t');

    Serial.print(rx.frameLost);
    Serial.print('\t');
    Serial.print(rx.failsafe);
    Serial.println('\t');
  }
}

void setup()
{
  Serial.begin(115200);
  Serial1.begin(100000, SERIAL_8E2_RXINV);
}

void loop()
{
  uint16_t t = micros();
  if(readSBUS())
  {
    // uint16_t dt1 = micros() - t;
    // Serial.print("dt1 ");
    // Serial.print(dt1);
    // Serial.print('\t');
    
    decodeSBUS(frame);
    printRx(1);

    // uint16_t dt2 = micros() - t;
    // Serial.print("dt2 ");
    // Serial.print(dt2);
    // Serial.print('\t');

    // Serial.print(rx.throttle);
    // Serial.print('\t');
    // Serial.print(rx.roll);
    // Serial.print('\t');
    // Serial.print(rx.pitch);
    // Serial.print('\t');
    // Serial.print(rx.yaw);
    // Serial.print('\t');

    // Serial.print(rx.armSwitch);
    // Serial.print('\t');
    // Serial.print(rx.switch3);
    // Serial.print('\t');
    // Serial.print(rx.switch4);
    // Serial.print('\t');
    // Serial.print(rx.switch5);
    // Serial.print('\t');
    // Serial.print(rx.switch6);
    // Serial.print('\t');

    // Serial.print(rx.pot1);
    // Serial.print('\t');
    // Serial.print(rx.pot2);
    // Serial.print('\t');

    // Serial.print(rx.frameLost);
    // Serial.print('\t');
    // Serial.print(rx.failsafe);
    // Serial.println('\t');

    // uint16_t dt = micros() - t;
    // Serial.print("dt ");
    // Serial.println(dt);
    // Serial.println();
  }
  ++countTot;

  // if(countTot % 1000 == 0)
  // {
  //   Serial.print(countSBUS);
  //   Serial.print('\t');
  //   Serial.print(countTot);
  //   Serial.println('\t');
  // }

  // uint16_t dt = t - micros();
  // Serial.println(dt);
}

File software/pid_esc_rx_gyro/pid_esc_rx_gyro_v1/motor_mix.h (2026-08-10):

constexpr uint16_t MOTOR_STOP     = 0;
constexpr uint16_t MOTOR_IDLE     = 130;
constexpr uint16_t MOTOR_MAX      = 2047;

struct MOTOR_POWER{
  uint32_t motor1;
  uint32_t motor2;
  uint32_t motor3;
  uint32_t motor4;
};

MOTOR_POWER computePower(float throttle, float roll, float pitch, float yaw)
{
  roll  = constrain(roll,  -1000, 1000);
  pitch = constrain(pitch, -1000, 1000);
  yaw   = constrain(yaw,   -2000, 2000);

  MOTOR_POWER pwr = {0, 0, 0, 0};
  
  float throttleCmd = MOTOR_IDLE + throttle * (MOTOR_MAX - MOTOR_IDLE);

  pwr.motor1 = constrain(throttleCmd - roll - pitch - yaw, MOTOR_IDLE, MOTOR_MAX);
  pwr.motor2 = constrain(throttleCmd - roll + pitch + yaw, MOTOR_IDLE, MOTOR_MAX);
  pwr.motor3 = constrain(throttleCmd + roll - pitch + yaw, MOTOR_IDLE, MOTOR_MAX);
  pwr.motor4 = constrain(throttleCmd + roll + pitch - yaw, MOTOR_IDLE, MOTOR_MAX);

  return pwr;
}

void printMPower(MOTOR_POWER pwr, bool doIt = true)
{
  if(doIt)
  {
    Serial.print(pwr.motor1);
    Serial.print('\t');
    Serial.print(pwr.motor2);
    Serial.print('\t');
    Serial.print(pwr.motor3);
    Serial.print('\t');
    Serial.println(pwr.motor4);
  }
}

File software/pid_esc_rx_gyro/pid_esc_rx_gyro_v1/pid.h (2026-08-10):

#define ROLLING_WINDOW_SIZE 256

struct PID_AXIS{
  float roll;
  float pitch;
  float yaw;
};

struct PREVIOUS_GYRO{
  float roll;
  float pitch;
  float yaw;
};

struct ROT_AXIS{
  uint32_t roll;
  uint32_t pitch;
  uint32_t yaw;
};

struct PID{
  float p;
  float i;
  float d;
};

struct ROLLING_WINDOW{
  float roll[ROLLING_WINDOW_SIZE];
  float pitch[ROLLING_WINDOW_SIZE];
  float yaw[ROLLING_WINDOW_SIZE];
};

constexpr PID roll_coeff  = {1.00, 4.00, 0.00};
constexpr PID pitch_coeff = {1.00, 4.00, 0.00};
constexpr PID yaw_coeff   = {1.00, 4.00, 0.00};

constexpr float dt = 0.001;

PID_AXIS pid = {0.0, 0.0, 0.0};

PID updateErrors(float current_control_rate, float current_gyro_rate, float previous_gyro_rate, uint32_t &currentIndex, float (&rolling_window)[ROLLING_WINDOW_SIZE], float &integral)
{
  PID errors = {0.0, 0.0, 0.0};

  float current_error = current_control_rate - current_gyro_rate;
  
  errors.p = current_error;
  errors.d = -(current_gyro_rate - previous_gyro_rate) / dt;

  if(ROLLING_WINDOW_SIZE != 0)
  {
    float oldest_error = rolling_window[currentIndex];
    rolling_window[currentIndex] = current_error * dt;
    currentIndex = (currentIndex + 1) % ROLLING_WINDOW_SIZE;
    errors.i = integral + current_error * dt - oldest_error;
    integral = errors.i;
  }
  else
  {
    errors.i += current_error;
  }

  return errors;
}

void computePid(float control_roll_rate, float control_pitch_rate, float control_yaw_rate, float gyro_roll_rate, float gyro_pitch_rate, float gyro_yaw_rate)
{
  static PID roll_errors  = {0.0, 0.0, 0.0};
  static PID pitch_errors = {0.0, 0.0, 0.0};
  static PID yaw_errors   = {0.0, 0.0, 0.0};

  static float roll_integral = 0;
  static float pitch_integral = 0;
  static float yaw_integral = 0;

  static PREVIOUS_GYRO previous_gyro_rate = {0.00, 0.00, 0.00};

  static ROT_AXIS currentIndex = {0, 0, 0};
  static ROLLING_WINDOW rolling_window;

  roll_errors  = updateErrors(control_roll_rate,  gyro_roll_rate,   previous_gyro_rate.roll,  currentIndex.roll,  rolling_window.roll,  roll_integral);
  pitch_errors = updateErrors(control_pitch_rate, gyro_pitch_rate,  previous_gyro_rate.pitch, currentIndex.pitch, rolling_window.pitch, pitch_integral);
  yaw_errors   = updateErrors(control_yaw_rate,   gyro_yaw_rate,    previous_gyro_rate.yaw,  currentIndex.yaw,    rolling_window.yaw,   yaw_integral);

  previous_gyro_rate.roll  = gyro_roll_rate;
  previous_gyro_rate.pitch = gyro_pitch_rate;
  previous_gyro_rate.yaw   = gyro_yaw_rate;

  pid.roll  = roll_coeff.p * roll_errors.p   + roll_coeff.i * roll_errors.i   + roll_coeff.d * roll_errors.d;
  pid.pitch = pitch_coeff.p * pitch_errors.p + pitch_coeff.i * pitch_errors.i + pitch_coeff.d * pitch_errors.d;
  pid.yaw   = yaw_coeff.p * yaw_errors.p     + yaw_coeff.i * yaw_errors.i     + yaw_coeff.d * yaw_errors.d;
}

void printPID(bool doIt = true)
{
  if(doIt)
  {
    Serial.print(pid.roll);
    Serial.print('\t');
    Serial.print(pid.pitch);
    Serial.print('\t');
    Serial.println(pid.yaw);
  }
}

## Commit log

2026-06-10 change gyro DLPF config
2026-06-15 pid_esc_rx_gyro code is ready to fly. PID tuning remaining.
2026-06-21 PCB first version. Not wired yet
    [Carrier_PCB.kicad_pcb, Carrier_PCB.kicad_sch]
2026-06-22 Update PCB. Not wired yet
    [Carrier_PCB.kicad_pcb, Carrier_PCB.kicad_sch]
2026-07-17 add fc sensortest
    [ismd_fc_sensortest.kicad_sch]
2026-07-17 upload schematics
    [BMP581.step, DPS310XTSA1.step, DPS368.step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]
2026-07-17 work on sensortest
    [bmp581.kicad_sch, dps368.kicad_sch, ismd_flight_computer.csv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]
2026-07-17 sensortest chematics
    [ismd_fc_sensortest.kicad_sch]
2026-07-18 schematic corrections
    [b1_bmp581.kicad_sch, b2_dps368.kicad_sch, b3_icp20100.kicad_sch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]
2026-07-18 add drone board graphics in svg format
2026-07-18 sensortest work
    [b1_bmp581.kicad_sch, b2_dps368.kicad_sch, b3_icp20100.kicad_sch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]
2026-07-18 Expand README hardware folder and PCB design descriptions
2026-07-18 added mounting holes to sensortest
    [i1_icm42688p.kicad_sch, ismd_fc_sensortest.kicad_pcb, ismd_fc_sensortest.kicad_sch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]
2026-07-19 remove mpu holes in sensortest
    [Carrier_PCB_v2.kicad_pcb, ismd_fc_sensortest.kicad_pcb, ismd_fc_sensortest.kicad_sch]
2026-07-22 power reg
    [b1_bmp581.kicad_sch, b2_dps368.kicad_sch, b3_icp20100.kicad_sch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]
2026-08-10 ready to fly
    [Carrier_PCB_v2.kicad_pcb]
2026-10-27 sample flight logs
